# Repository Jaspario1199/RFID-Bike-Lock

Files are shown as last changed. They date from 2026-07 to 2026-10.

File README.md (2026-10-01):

# RFID Bike Lock

**Current DFM print prototype: [VELOX rev3f](releases/rev3f/README.md).** Use its 16 labeled STEP files and [build guide](releases/rev3f/PRINT_BUILD_REV3F.md), with the corrected model frozen at `releases/rev3f/snapshot/cad/cnc_casing_cq.py`. Coupons first; spool deferred; printer profile still pending. The older source/export folders and instructions below are retained as historical lineages and must not be mixed with rev3f.

A frame-mounted, RFID/NFC-unlocked bike lock with a retractable anti-cut steel cable.

The lock is a stainless-steel clamshell cylinder that clamps permanently onto the bike
frame over a compressible liner. A retractable steel cable lives on a spring-loaded spool
in the bottom of the housing; you pull it out, loop it through the wheel or around a rack,
and click the cable head into a latch on top. Tapping an authorized NFC fob (or phone —
see the design doc for the honest caveats) fires a solenoid that pulls the locking pin and
releases the cable, which then reels itself back in.

## Repo map — everything lives on one branch, organized by iteration

| Path | What it is |
|---|---|
| [`DESIGN.md`](DESIGN.md) | The full engineering design document: user workflow, electronics, wiring, power budget, mechanical dimensions, water/power hardening (§4.5), security analysis |
| [`BOM.md`](BOM.md) | Bill of materials — every part, quantity, estimated price (v0.8 all-M3 heat-set fastener standard + v0.8.3 weatherproofing items) |
| [`BUILD.md`](BUILD.md) | The authoritative bench build sequence + print-orientation table (`--dfm`) |
| [`ASSEMBLY.md`](ASSEMBLY.md) | Assembly/DFM audit + v0.8.3 weatherproofing steps (printed v0.8 lineage) |
| [`CAD_METHOD.md`](CAD_METHOD.md) | **Portable method doc** — how to model and verify mechanical parts with an agent: the gate catalogue, the iteration loop, honesty rules, and an opening prompt for a new project |
| [`BENCH_BUILD.md`](BENCH_BUILD.md) | **Start here for the electronics** — seven bench stages using only the delivered parts, with workarounds for the TP4056/AMS1117/cap that haven't arrived |
| [`WIRING.md`](WIRING.md) | **The electrical build in detail** — starts with the [wiring diagram](renders/electrical/wiring_diagram.png) — power domains, full net list, the RC522 3.3 V trap, driver-card layout, build order with expected measurements, failure table |
| [`CAD_AUDIT.md`](CAD_AUDIT.md) | **Build audit of the CNC casing (rev 3e)** — what `--audit` checks beyond the geometry gates (wire/connector envelopes, nuts, plugs, thread engagement, pin insertion, machining numerics), every defect it found and what moved |
| [`ASSEMBLY_CNC.md`](ASSEMBLY_CNC.md) | **The step-by-step build manual for the current CNC casing (rev 3e)** — print settings, every screw, bench checkpoints, stage-by-stage assembly, troubleshooting |
| [`INTERNALS.md`](INTERNALS.md) | **How every electronic mates inside** — per-part contact faces, screws, wiring paths, keyed to `renders/internals/` |
| [`CNC_CASING.md`](CNC_CASING.md) | **The machined-casing redesign** — CNC-first architecture (tube-half chassis + inside-out bolted boxes, bottom hinge pin + one guarded closure screw, centred spool puck, 60° swing gated, electronics stack-up gated, no inserts), DFM rulebook, decisions; model `cad/cnc_casing_cq.py`, STEP `cnc-design/step/`, drawings `cnc-design/drawings/`, renders `renders/cnc/` |
| [`firmware/`](firmware/) | Arduino sketch (v1, ready to flash) + bench bring-up guide |
| [`cad/bike_lock_cq.py`](cad/) | **The single source of truth**: parametric CadQuery model with built-in verification gates (`--gaps`, `--matrix`, `--sweep`, `--support`, `--dfm`) |
| [`newest-design/`](newest-design/) | **LEGACY printed CAD: frozen STEP set (v0.8.3) + MANIFEST** — print/import from here  |
| [`archive/`](archive/) | **Every previous iteration** (v0.2 → v0.7), one folder per version |
| `renders/` | Current assembly renders (closed / open / exploded) |
| `step/`, `stl/` | *Generated build outputs — gitignored; `python cad/bike_lock_cq.py` regenerates them* |

## Iteration index (newest first)

`releases/rev3f/` holds the current DFM print prototype; `newest-design/` holds the older printed lineage; each `archive/vX/` folder holds the frozen **STEP files** for that iteration (per-part
`placed/` set + full assembly + combined multibody) and a `MANIFEST.md` describing exactly
what changed. Older bulk formats (STL, doc snapshots) were trimmed for clarity — git
history preserves every byte.

| Iteration | Where | What it was |
|---|---|---|
| **v0.8.3** (legacy) | [`newest-design/`](newest-design/) | Environmental + DFM hardening: latch-bore & drum weep drains, TPU USB port plug, flush-printing cart, `--dfm` orientation scan, 6 V-rail power option, weatherproofing BOM |
| v0.8.2 | git history of `newest-design/` (MANIFEST §v0.8.2) | Structural audit: `--support` gate, all 17 under-supported heat-set holes fixed, driver card moved onto the pedestal cart (Option C) |
| v0.8 / v0.8.1 | same MANIFEST, §v0.8/§v0.8.1 | All-M3 heat-set fastener rebuild + snug-fit pocket tuning (Ø4.0 locked) + test coupon |
| v0.7 | [`archive/v0.7/`](archive/v0.7/) | Electronics as placed reference bodies; driver relocation; release process begins |
| v0.5–v0.6 | `cad/` git history | Spine+door consumer-install architecture; hinge rod; verification gates born |
| v0.3–v0.4 | [`archive/v0.3/`, `archive/v0.4/`](archive/) | Early CadQuery restructure + slim-top architecture (source + STEP kept) |
| v0.2 | [`archive/v0.2-openscad/`](archive/v0.2-openscad/) | Original OpenSCAD sketch |

## Status

**Design phase — firmware written, nothing physically built yet.** The next milestones
(detailed at the end of `DESIGN.md`) are:

1. Breadboard the electronics (Nano + PN532 + solenoid) and prove the unlock flow —
   the firmware and a step-by-step bring-up guide are waiting in `firmware/`
2. 3D-print the v1 housing (PETG first article; ASA for the outdoor unit) from
   `newest-design/` — print orientations in `BUILD.md` §3b
3. Fabricate the stainless housing

## Key design decisions so far

- **MCU:** Arduino Nano (upgrade path to 3.3 V Pro Mini for longer battery life)
- **Reader:** PN532 NFC module. Keys: NTAG213 sticker on the owner's phone case +
  keychain fobs (owner has an iPhone, which can't act as a hobby NFC key, so no
  companion app is planned)
- **Battery:** 103450 LiPo pouch 2000 mAh (protected) + TP4056 USB-C charge board — the 18650 stopped packaging at v0.4
- **Locking:** insert-to-lock needs **no power** (ramped cable head snaps past a spring pin);
  power is only used for the ~300 ms unlock pulse and brief scan windows
- **One-size-fits-all fit:** a printed TPU *finned* liner (fins bend instead of foam
  crushing, so it stays snug for years) covers Ø32–46 mm down tubes, closure
  detents fine-tune preload, and an included shim sleeve extends down to Ø27 mm skinny
  steel frames — see `DESIGN.md` §6.2
- **Self-guarding closure:** the only screw holding the housing shut sits at the bottom
  of the latch bore, so the locked cable head physically covers it — the case can't be
  unscrewed off the frame while the bike is locked (`DESIGN.md` §6.4). Note: as of the
  v0.6 CAD audit, four *other* service joints (hatch, spine cover, hinge cap, lid) are
  ordinary external screws reachable on the locked bike without unlocking anything —
  see `DESIGN.md` §7 for the honest security consequences and the production mitigation
  plan
- **v1 housing is 3D printed** (ASA for outdoor UV resistance); the latch keeps a steel
  pin + bushing even in plastic
- **Dead-battery behavior:** fail-secure — a dead battery stays locked, and the USB-C
  charge port doubles as the sole emergency input: any phone power bank runs the lock
  instantly for an unlock (`DESIGN.md` §8). There is no cam-lock backstop — it was
  deleted at v0.4 (the slim top never had a wall tall enough for its barrel)

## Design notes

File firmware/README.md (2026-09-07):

# Firmware

Three builds of the same lock, same behaviour and same key set — pick the one that matches
your board:

| Sketch | Board | Reader wiring |
|---|---|---|
| `rfid_bike_lock_esp32/` | **Arduino Nano ESP32** (3.3 V) — *the one in hand* | RC522 direct, **no level shifters** |
| `rfid_bike_lock_rc522/` | classic Nano / Uno (5 V) | RC522 via 1 k / 2 k dividers |
| `rfid_bike_lock/` | classic Nano / Uno (5 V) | PN532 over I2C |
| `rc522_test/` | **diagnostic** — Nano ESP32 | 40 lines: prints VersionReg + any card UID |
| `hw_selftest/` | **diagnostic** — Nano ESP32 | serial menu, exercises LEDs / buzzer / buttons / reader / solenoid / A0 one at a time |

## Nano ESP32 build

1. **Boards Manager** → install **"Arduino ESP32 Boards"**, then select *Arduino Nano ESP32*.
2. **Library Manager** → install **MFRC522** (by GithubCommunity).
3. Wire the RC522 straight to the board — both are 3.3 V parts:

| RC522 | Nano ESP32 |
|---|---|
| SDA (SS) | D10 |
| SCK | D13 |
| MOSI | D11 |
| MISO | D12 |
| RST | D4 |
| 3.3V | **3V3** |
| GND | GND |

4. Panel I/O is the same as the other builds: green button D3, red button D2, red LED D8,
   green LED D9, buzzer D6, solenoid gate D5, battery sense A0.

**Differences from the AVR builds, all platform plumbing:**

- **Deep sleep resets the chip**, so the whole scan window lives in `setup()` and the sketch
  deep-sleeps at the end of it. `loop()` never runs. Wake is ext0 on the green button.
- **Tags live in Preferences (NVS)**, not EEPROM. Same 8-byte record layout.
- **The ADC is 12-bit against 3.3 V**, so the battery maths differ. The 100 k : 100 k divider
  is unchanged.
- **`DEV_NO_SLEEP` is 1 by default.** Deep sleep kills the USB peripheral, so the IDE cannot
  reset the board into its bootloader and uploads fail with *"No DFU capable USB device
  available"* until you double-tap RESET by hand. With this switch on, the board idles awake
  between scan windows, USB stays alive and uploads just work. **Set it to 0 for the battery
  build** — idling awake costs roughly ten times the current of deep sleep, and the stage 7
  sleep measurement is meaningless with it on.
- **Upload failing anyway?** Double-tap the RESET button; the RGB LED pulses green in
  bootloader mode. Re-select the port (it changes in DFU mode) and upload.
- **Factory reset:** hold **both buttons** while powering up or pressing reset, for 1.5 s.
  Alternating LEDs and three beeps confirm it; the next wake re-enrolls a master.
- **Reader power gating is off by default** (`READER_POWER_GATED 0`). The IRF4905 you have is
  marginal at 3.3 V gate drive — its threshold is −2 to −4 V and 3.3 V logic can only reach
  −3.3 V. Fit the logic-level AO3401 from the SOT-23 kit before enabling it.

⚠️ **Honest caveat on battery life.** The Nano ESP32 is not a low-power board: the onboard
USB bridge, RGB LED and regulator all draw current in deep sleep, and reported figures are
milliamps rather than the microamps the bare ESP32-S3 can reach. Measure it (BENCH_BUILD stage
7) before trusting any battery-life estimate. If it comes in high, the fix is a bare
ESP32-S3 module or the 3.3 V Pro Mini path, not a firmware change.

---

Two sketches, one state machine (`../DESIGN.md` §5, pin map §4.2):

| Sketch | Reader | Use |
|---|---|---|
| `rfid_bike_lock_rc522/` | **RC522** (the Arduino kit board, SPI) | **build this first** — it is the reader the owner has, and the rev 3c housing is sized for it |
| `rfid_bike_lock/` | PN532 (I2C) | drop-in alternative if the RC522's range through the lid disappoints |

The two files differ only in the reader driver block (`pn532On/pn532Off/readTag`).

## RC522 wiring (hardware SPI)

| RC522 pin | Nano pin | Note |
|---|---|---|
| SDA (SS) | D10 | |
| SCK | D13 | |
| MOSI | D11 | |
| MISO | D12 | |
| RST | D4 | (D9 is the green LED) |
| IRQ | — | unused |
| 3.3V | **3V3 via the AO3401 gate** (D7) — bench step 1: straight to the Nano's 3V3 pin | the RC522 is a 3.3 V part; never 5 V on its VCC |
| GND | GND | |

## Panel I/O (both sketches)

| Part | Nano pin | Wiring |
|---|---|---|
| **GREEN button** (wake / open the scan window) | D3 (INT1) | one leg to D3, the other to GND; internal pullup. Only sleep wake source |
| **RED button** (tap = cancel the window, hold 5 s = admin mode) | D2 (INT0) | same, to GND |
| Red LED | D8 | through 470 Ω to GND |
| Green LED | D9 | through 470 Ω to GND |
| **Buzzer (ACTIVE)** | D6 | (+) to D6, (−) to GND. An active buzzer makes its own tone from DC |

Sounds: chirp on wake · two chirps on unlock · long buzz on a denied tag or a dead reader ·
three on admin mode · one long on low battery.

**Passive buzzer instead?** It needs a driven square wave. Replace the body of `beep()` with
`tone(PIN_BUZZER, 2700); delay(onMs); noTone(PIN_BUZZER);`. Note `tone()` uses Timer2 —
harmless here, but it will fight any library that wants that timer. The active one is the
simpler choice for the boxed unit; keep the passive one for the bench if you want pitch.

⚠️ A buzzer is a coil: keep it off the reader's gated rail and add a 1N5819 across it if you
ever drive it through a transistor rather than straight off the pin (an active buzzer draws
~25 mA, inside the Nano's 40 mA per-pin limit).

The Nano drives the RC522's SPI inputs at 5 V logic. Every RC522 kit tutorial does this and
it works, but it is out of spec; for the boxed unit put 1 kΩ in series with SS/SCK/MOSI/RST
(the MISO line is 3.3 V → Nano, fine).

## Setup

1. **Arduino IDE** → board *Arduino Nano*, processor *ATmega328P* (pick
   *Old Bootloader* if upload fails on a clone).
2. **Library:** install **Adafruit PN532** via Library Manager (pulls in Adafruit BusIO).
3. **PN532 module DIP switches → I2C mode:** on Elechouse-V3-style boards set
   `SEL0 = ON (1)`, `SEL1 = OFF (0)`. Boards silk-screen this next to the switches —
   trust the silkscreen if it disagrees.

## Bench bring-up (do these in order — don't wire everything at once)

| Step | Wire up | Expect |
|---|---|---|
| 1 | Nano + PN532 only (5 V, GND, A4→SDA, A5→SCL). Temporarily jumper D7's P-MOSFET out: power PN532 straight from 5 V. Serial monitor @115200 | On button press (D3→GND): `[wake]`, then tap a fob → `[scan] uid=…`. First tag ever tapped becomes **master** |
| 2 | Add the P-MOSFET power gate on D7 | Same behavior; PN532 LED only lights during the 10 s window |
| 3 | Add LEDs (D8 red, D9 green) | Denied tag → 2 red blinks; authorized → 1 s green |
| 4 | Add IRLZ44N + flyback diode + solenoid, **on a bench supply or fresh battery** | Authorized tap → 300 ms clunk |
| 5 | Measure sleep current (multimeter in series with battery, after the window expires) | Stock Nano: ~1.5–3 mA. If you see 20 mA+, the Nano never slept — check nothing is holding D3 low |

## Behavior recap

- **Press wake button** → 10 s scan window (green blip at start).
- **Authorized tag** → solenoid pulse, green 1 s, sleep.
- **Unknown tag** → red ×2, window stays open.
- **Low battery** (<3.5 V) → red ×3 right after wake, then continues normally.
- **First boot** → red/green alternating: the first tag tapped becomes the master
  (kept even through battery swaps; stored in EEPROM).
- **Hold button 5 s during the window** → admin mode: red/green alternating, tap
  **master** to confirm, then tap any tag to add (green ×3) or remove (red ×3) it.
  Master itself can't be removed. 15 s idle exits.
- **PN532 unresponsive** → fast red ×5 (check wiring/DIP switches).

## Config knobs (top of the sketch)

`SCAN_WINDOW_MS`, `SOLENOID_PULSE_MS`, `ADMIN_HOLD_MS`, `VBAT_LOW`, `MAX_TAGS`, and
`#define DEBUG` — comment DEBUG out for the battery-powered unit.

## Factory reset

Flash `File → Examples → EEPROM → eeprom_clear` once, then re-flash the lock sketch:
next boot re-runs master enrollment.

## Known v1 limitations (by design — see DESIGN.md)

- Auth is UID-matching only; UIDs are cloneable. v2 = challenge–response (HCE app).
- No cable-state sensor: an authorized tap pulses the solenoid whether or not the
  cable head is latched. Harmless; a latch microswitch is a v2 nicety.
- Phones can't act as keys directly (iPhone: Apple blocks it; Android: random UID per
  tap) — the permanent plan is fobs + an NTAG213 sticker on the phone case.

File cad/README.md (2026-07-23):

# CAD — parametric housing model (v0.6, CadQuery → STEP)

`bike_lock_cq.py` is the source of truth: a parametric [CadQuery](https://cadquery.readthedocs.io)
model that builds true BREP solids and exports **STEP** (SolidWorks-ready) and STL for
every part. Every dimension from DESIGN.md §6 is a named variable at the top of the file.

**Status: v0.6** — closure/hinge/verification overhaul on top of the v0.5 "spine + door"
architecture (still current: the door is a light arc panel that verifiably swings clear,
0–110°, machine-checked; pod, bay, and slim Y-axis drum all live on the body's right
side; the entry corridor is kept empty by construction). v0.6 was driven by a full
geometric audit that found and fixed 12 defects (D1–D12, all machine-confirmed) the old
verification missed: the closure screw now reaches a real M4 insert over a solid floor
instead of piercing into the tube cavity (D1/D2); the lid, spool cover, hatch, and bay
screws all land on working pilots instead of open cavities (D3–D6); the two glued end
plugs and their blind pins are gone, replaced by a single Ø4×~152 stainless **hinge rod**
with an integral turned head and a screwed **hinge cap** (owner request, no glue); the
sealed wire spine opened into a lay-in raceway closed by a screwed **spine_cover** (owner
request); the liner is retained by dovetail keys instead of adhesive/foam tape; the
battery bay was repacked so the LiPo and TP4056 no longer contest the same floor (D11);
and a merged pedestal/solenoid hole pair was separated (D12). Verification grew a
`--gaps` exact-distance mode, `--matrix`'s clash floor tightened to 0.01 mm³ (`--strict`
0.001), the sweep's moving set now includes `liner_left` (the old fixed-set sweep is
what hid D10, a liner gouge), and `--export-assembly` regenerates every STEP output off
one `placements()` table — see **Verification** below for all four modes.
v0.3 and v0.4 are preserved in `archive/`. Rendered and verified; nothing test-printed.

## Working in SolidWorks

**Fastest start: open `step/bike_lock_combined.step`** — all 12 parts positioned, as a
single multibody file (imports the same reliable way as the individual parts; each body
is separately selectable/hideable in the Solid Bodies folder). `bike_lock_assembly.step`
is the same content as a true STEP *assembly* with named, colored components — some
SolidWorks configurations open it blank; if so, untick Tools → Options → Import →
"Enable 3D Interconnect" and reopen, or just use the combined file. Neither carries
mates (STEP can't); parts are frozen in their correct positions. The optional `shim`
isn't included since it occupies the liner's space.

Open any `step/<part>.step` directly — each imports as a clean solid body (real faces,
direct-editable, measurable, assemblable, FEA-able). STEP carries no feature tree; to
iterate parametrically either edit `bike_lock_cq.py` and re-export, or rebuild a part
natively in SW using the parameter block as the spec.

**Native SW assembly in 2 minutes (no mates needed):** use `step/placed/01..12_*.step`
— every part is exported already moved/rotated into its final global position (including
the lid, spool cover, hinge rod, hinge cap, and spine cover). In a new assembly: Insert Component → pick a file →
press the green ✓ WITHOUT clicking in the viewport (drops at the assembly origin = its
correct position). Repeat through the numbered list; every component arrives placed and
Fixed. These are single-solid files — the format that imports/display most reliably.

**If a multibody/assembly STEP opens with a populated tree but a blank viewport:** show
the bodies (right-click Solid Bodies folder → Show), press `f`; if still blank, untick
Options → Performance → "Enhanced graphics performance" (restart), or as a last resort
enable software OpenGL — and verify the file itself in eDrawings.

To regenerate everything: `pip install cadquery` then `python bike_lock_cq.py`
(or `python bike_lock_cq.py lid drum_module` for specific parts).
`archive/v0.2-openscad/legacy_bike_lock_v02.scad` (repo root) is the retired OpenSCAD v0.2, kept for reference;
`render_v03.scad` only composites the exported STLs for preview renders.

## v0.7 part set (14 printed parts + 1 lathe rod + 11 electronics reference bodies)

v0.7 adds machine-verified ELECTRONICS PACKAGING: every BOM electronic is a
placed reference body (89+ numbering, green in renders, in `step/placed/` for
SolidWorks placement work - NOT printed), and every board has a modular
holder: the driver card (42×10.7 cut perfboard) sits on two Ø7 crown bosses
on the pod's −y strip (x66/x96, 2× M3 ST, <30 mm from the solenoid — the bay
perf rack was deleted, see BUILD.md §2), `nano_clamp` (edge-standing Nano in
a pod wall recess, clamp bar on crown bosses), TP4056 flat cradle rails (USB
correctly through the wall - the v0.5 vertical slot pointed it at the floor),
MT3608 end-posts on the pedestal tower, edge-standing LiPo with rail + wall +
block face. `89_mock_cable_head` models the latched cable head (Ø10 head,
ring groove at the plunger line, ~1.6 mm plunger engagement). The --gaps
table asserts the packaging: solenoid-to-lid 1.0, plunger-tail-to-button 1.0
(tail MUST be trimmed to x98), board recess seats, cell containment,
cable-head latch engagement - 292 checks.

| Part | Role |
|---|---|
| `body` (v0.7) | right clamp + asymmetric pod + latch boss + **open wire-spine raceway** + pedestal pads + swept closure pockets (D1/D2 fixed: the screw now reaches a real insert over a 3.7 mm solid floor instead of piercing the flange) |
| `door` (v0.7) | light arc panel + closure hook flange & low insert pad + hinge knuckles — verified to swing clear |
| `bay_module` (v0.7) | right-side brick (LiPo stood on edge to clear the TP4056 block — D11 — plus zip grids), slim Y-axis drum Ø68×32, snout; bolts by 4× M4 pan screws from inside the bore, now fully sub-flush (D5) |
| `bay_hatch` (v0.7) | bottom cover, doubles as the component **tray** (nesting pad + zip-anchor grid); 2× M3 machine screws into heat-sets on the external face — leave a service loop so pulling the tray doesn't strain the cell leads |
| `pedestal_cart` (v0.7) | solenoid mount on the pad system; attach pads moved off the solenoid holes (D12; VERIFY dims live here) |
| `lid` (v0.7) | window skin, NFC ring, button dish, PN532 pocket on drop-bosses (4× nylon M2.5, no tape); now has real pilots in the body rim (D3) — 4× M3 CS machine into heat-sets |
| `liner_right` / `liner_left` (v0.7) | TPU fit system, dovetail-keyed into each shell half (no adhesive); `liner_left` carries the closure's swept-form transit window (D10 fix) |
| `shim` (v0.7) | TPU fit-system C-ring extension (unchanged; not in `placements()` — occupies the liner's space) |
| `spool_cover` (v0.7) | outboard (+Y) drum face plate; screw circle moved onto the ring-wall boss and re-clocked so one screw sits on the vertical axis (D4/D5 fix) |
| `hinge_cap` (v0.7) | screwed tail cap capturing the hinge rod's 0.5 mm axial float — replaces the glued end plugs (D7) |
| `spine_cover` (v0.7) | screwed cover plate closing the wire raceway, drip grooves on the underside (owner request) |
| `hinge_rod` *(lathe, not printed)* (v0.7) | single Ø4.00×~152 mm 303-stainless rod, integral Ø6.0×1.6 turned head — one lathe op from Ø6 bar |

The pedestal still uses the standardized flat-pad system (12 mm pads, tops at z=32).

Assembly-audit fixes implemented (ASSEMBLY.md §3): **plunger-as-pin** (Ø6.6 channel, no
separate pin/spring/coupling), the **single hinge rod** (owner request, replacing the two
blind hinge pins and their glued end plugs — D7), and card-edge board pockets.

## v0.8 — all-M3 heat-set fastening (owner request)

For a super-refined printed prototype, **every threaded joint is now an M3 machine screw
into an M3 brass heat-set insert** — no self-tapping-into-plastic anywhere. The conversion
replaced every Ø2.5 self-tap pilot with an INS3 pocket (Ø4.1×6.5), switched the bay screws
from M4 self-tap to M3 socket-cap into inserts, dropped the closure screw from M4 to a short
M3 heat-set (Ø4.0×L3.8, the pad is only 3.4 mm deep), and moved all cover parts to
machine-flat countersinks (ISO 10642, 90°) since they now thread into inserts rather than
self-tap. Two carve-outs, both forced by an external part and both flagged in the BOM:
- **Solenoid → M2.5** — the JF-0530B's own mounting tabs are drilled M2.5; an M3 screw
  physically won't pass, so this one joint keeps an M2.5 brass heat-set.
- **PN532 → M3 nylon** — the antenna loop wraps the whole board perimeter, so brass/steel at
  the 4 corner holes sits in the 13.56 MHz field and kills read range; the M3 standard is
  kept but the screws are nylon into printed bosses (no insert). All 4 corners, no safe subset.

Two geometry side-effects were handled and re-gated to 0: the spool-cover screws couldn't take
a Ø4.1 insert in the 2.5 mm-thin ring wall, so each of the 3 stations gained a small inboard
buttress that backs the insert without fouling the cover recess; and two vestigial features
(the nano-*sled* foot pilots and the deleted perf-rack's hatch cartridge screws) were removed.
Gate after conversion: **0 violations / 292 checks · 0 clashes · sweep 0.00 · corridor clean.**

## Verification (v0.6)

`bike_lock_cq.py` runs an entry-corridor interference check on every export automatically.
Four more checks run as explicit CLI modes — none of these ship parts, they only assert
things about the model:

- **`--sweep`** — rotates the door **and `liner_left`** 0–110° about the hinge against
  everything else and asserts 0 mm³ overlap at every step. The moving set used to be
  door-only against a body+bay+lid-only fixed set; that gap is exactly what hid D10 (a
  25.5 mm³ gouge through `liner_right`'s base ring at θ=10° that the body-side relief
  never covered because the liner never got its own).
- **`--matrix`** — full pairwise static-interference check over every part in
  `placements()`. The true-clash floor tightened from 1 mm³ to **0.01 mm³** (an OCC-noise
  study); `--strict` drops it further to **0.001 mm³**, which stays clean at exact
  tangency but is finer than FDM tolerance can act on, so it's opt-in.
- **`--gaps`** — exact minimum-distance check (`BRepExtrema_DistShapeShape`) on every
  placed pair, layered on top of the boolean clash gate so a true overlap and an intended
  tight fit can't be confused. Each pair is checked against `GAP_SPECS`: a `(min, max)`
  mm band (e.g. liner-in-bore 0.05–0.30), the `CONTACT_OK` sentinel for clamped faying
  faces where 0.00 mm is correct and only actual interpenetration should fail (seam/hook,
  pod rim, pedestal pads, hinge-rod head seat, hinge-cap seat, spine-cover seat), or the
  plain clash-only floor if the pair is unlisted. `feature_probes()` adds local box probes
  for fits a whole-pair distance can't isolate on its own — a 0.00 mm contact anywhere
  else on the same pair would swamp the measurement otherwise — currently the knuckle
  axial gap (0.6–1.0 mm at 6 x-stations, asserting `hinge_gap`'s ~0.8 mm net float) and
  the hinge-rod running-bore fit (0.05–0.15 mm, checked separately in `body` and `door`).
- **`--export-assembly`** — regenerates `step/placed/`, the combined multibody STEP, and
  the assembly STEP, all off the same `placements()` table `--matrix` and `--gaps` read,
  so the three outputs can't drift apart from each other.

All four currently PASS.

## Design principles applied in v0.2

Standard FDM design-for-manufacturing + product-design practice:

- **One radius family** (R14 belt / R11 pod / R3 details / 1.2 mm edge breaks) so every
  surface looks like it belongs to the same object.
- **Drafted walls**: the pod tapers 1.8 mm base→lid, with the interior drafted the same
  amount → **uniform ~3 mm walls** everywhere (no massive solids; the latch boss and
  solenoid pedestal are gusseted/hollowed instead of solid).
- **The part line is a design line**: the closure skirt is the left half of a full
  wrap-around **belt band**, separated from the pod by a 0.8 mm shadow-gap groove — the
  seam reads as intentional, and the hidden-screw closure lives inside it.
- **Fairings, not intersections**: pod→tube and drum→body transitions are blended
  (teardrop), keeping overhangs ≤45° so the shells print without heavy support.
- **Chamfered bottom edges** everywhere a part meets the build plate; countersunk lid
  screws; recessed USB niche; embossed NFC target ring so the user knows where to tap.
- **Wiring is modeled, not implied**: two clip-lip floor raceways (RF-zone ribbon x4–54,
  power/solenoid run x60–100), a driver tray over the Nano bay with wire notches and
  zip-tie holes, two battery saddles giving the 18650 holder a level bed (with zip-tie
  pass-unders), and two mushroom strain-relief posts for the lid's service loop.

## Print guide

| Part | Material | Orientation / notes |
|---|---|---|
| body (shell_right) | PETG first / ASA outdoors | pod-opening up; light support under belt + spine rib |
| door (shell_left) | PETG / ASA | split-face down, near-zero support |
| bay_module | PETG / ASA | hatch-faces down; supports under the drum ring arc only |
| bay_hatch | PETG / ASA | flat, no support — now the component tray, see drill-out note below |
| lid | PETG / ASA | top-face down on a smooth sheet (window skin + NFC ring print first) |
| pedestal_cart, hinge_cap | PETG | flat side down, minutes each |
| spine_cover | PETG / ASA | curved face up; dry-fit before drilling — see orientation/warp VERIFY below |
| liner halves, shim | TPU 95A | 2 perimeters, 15% infill, ~25 mm/s, fins vertical; keys separate — see dovetail VERIFY below |
| hinge_rod | 303 stainless bar, lathe | not printed — see "Hinge" in the change notes for the lathe callouts |

### Drill-out / bench ops after printing (new in v0.6)

- **Hinge bore.** Modeled finished at Ø4.2 (`HINGE_BORE`), but FDM print holes come out
  undersized and drooped — don't trust the as-printed bore. **Drill Ø4.2 straight through
  the body and door with the two shells closed and clamped together** (i.e. after the
  liner/closure dry-fit, not before): this crosses 8 interrupted knuckle segments, each
  ≤14 mm long (L:D ≤3.5), so it's a series of short through-holes, not deep-hole drilling
  — the printed pilot self-centers the bit. Blow out swarf before the liner or rod goes in.
- **Plunger channel.** `pin_ch_d` is modeled at `plunger_d + 0.6` = 6.6 mm. Ream to 6.5 mm
  only once the real JF-0530B plunger is measured — VERIFY before committing to the ream.
- **Dovetail groove.** The 60° groove/key pair is orientation-sensitive on FDM (layer
  lines cross the flank at an angle); print and slide-fit a short test length before
  committing a full liner print — see "Suggested first prints" below.
- **Spine cover.** Dry-fit on the r35 rabbet ledge before drilling the 2× M3 pilots — a
  bowed or under-radius print won't seat flush, and the 0.5 mm shadow-gap reveal makes
  any unevenness obvious.
- **Hatch/tray.** `bay_hatch` is now the component tray (nesting pad + zip-anchor grid),
  not just a cover — check the nesting pad registers flush with the remaining bay floor
  before loading components, and leave a lead service loop so removing the tray doesn't
  strain the LiPo/TP4056 wiring.

## VERIFY before printing (measure your actual parts)

- `sol_hole_dx` — mounting-hole spacing of the JF-0530B you receive (clones vary) —
  merged with the pedestal attach holes in v0.5 (D12); confirm before installing the
  M2.5 heat-sets
- `pn532_l/w/t` — your PN532 board (clone boards vary a couple of mm)
- PN532 corner mounting holes — `PN532_HOLE_INSET` (2.54 mm) assumes Elechouse V3
  corner holes at Ø3; clones may lack them, in which case the printed corner clips (same
  drop-bosses) are the fallback
- `button_d` — thread diameter of your wake button (12 mm nominal)
- ST flat-head countersink angle — modeled at 90° (`M3_ST_CS_D`/`M3_ST_CS_T`); confirm
  your self-tap screws are 80° or 90° before cutting countersinks to depth
- M4-short heat-set (Ø5.6×L3, closure) and M3/M2.5 brass insert dimensions — confirm the
  actual insert OD/length you buy against `INS4_D`, `INS3_D`/`INS3_T`, `INS25_D`/`INS25_T`
  before drilling insert pockets
- Plunger diameter — `pin_ch_d` (6.6 mm) is a placeholder for the 6.5 mm reamed channel;
  confirm against the real plunger (see drill-out note above)
- TP4056 slot width — confirm against your board before trusting the D11 bay repack
- Dovetail groove print-orientation test — slide-fit a short liner slice before running
  a full liner print
- Spine cover warp/orientation test — dry-fit flush on the rabbet ledge before drilling
- LiPo edge-stand fit — measure your actual 103450 pouch (`lipo_l/w/t`) against the
  on-edge bay repack (D11) before trusting it packable
- Donor spool: the drum interior is Ø61 × 28.5 (v0.5 slim drum) — check the reel you gut fits, or resize
  `drum_od`/`drum_w` (frame otherwise cut for 34.5 × 51 × 11 / 103450 + margin — measure
  yours against `lipo_*`)

## Known simplifications (TODO after first fit-check print)

1. Closure lip is a single snug hook — the 3 preload detent depths (DESIGN.md §6.4) get
   added once the on-bike fit is measured; `clr` (0.5) needs a fit print.
2. ~~Liner halves rely on friction + adhesive; dovetail keys into the shell come later.~~
   **SOLVED in v0.6:** a full-length 60° dovetail groove per shell half (mid-arc, one
   straight axial pass) with 4× 28 mm TPU keys sliding in from the front, captive both
   ways (blind stop + click-bump) — no adhesive anywhere in the liner retention path.
3. Shim is a plain C-ring approximation of the clip-over design.
4. Lid uses 4 M3 screws. In v0.6 these landed on **real pilots in the body rim for the
   first time** (D3 — v0.5's screws had no working pilots at all, two of them even fell
   inside the PN532 window's 1.2 mm skin) and drive into brass M3 heat-sets, so it's now
   an actual fastened joint rather than a nominal one. It is still externally removable
   on the locked bike — that's now documented as one of four such joints (hatch, spine
   cover, hinge cap, lid), not a uniquely accepted exception; see DESIGN.md §7 for the
   full consequence list and the production mitigation plan (security/one-way heads,
   staking, eventual hidden lid fastening).
5. Spool spring anchoring is not modeled — depends on the donor reel's spring.
6. The bay tunnels are functional but unblended boxes — the v0.6 industrial-design pass
   (bay-brick bottom chamfer, knuckle chamfers, lid inset/reveal, radius family) softened
   the visible skin, but a full cosmetic fairing pass on the bay tunnels still comes
   after fit is proven. The wire-spine rib itself is gone: it's now an open raceway under
   a separate screwed `spine_cover` (see the part table above), not a molded-in band.
7. The plunger nose needs its 45° ramp filed/ground by hand — 10 minutes with a file;
   the cable-head groove width (≥6.5 mm) must match, noted in DESIGN.md §6.4.

## Suggested first prints (cheap fit checks before the big ones)

1. **Liner test ring**: a 30 mm-long slice of the liner on a 30 mm slice of shell — clamp
   it on the actual bike, judge fin grip across a couple of other bikes too.
2. **Latch block only**: cut the latch boss region (X 45–115) using OpenSCAD's
   intersection with a cube — test bore, pin channel, solenoid pedestal, and the bench-mule
   square tang (DESIGN.md §6.4) with the real solenoid before printing full shells.

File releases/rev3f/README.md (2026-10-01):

# VELOX rev3f — prototype print-stage STEP files

16 individual solid STEP files, in millimetres, oriented as the build guide suggests and placed at Z=0. File names include order, part, material and revision. No assembly or purchased-component reference is included in the STEP folders.

1. Print the two fit coupons first, in their supplied orientations, and test the actual latch hardware.
2. Print electronics and latch parts after accepting the fits. The printed latch parts are fit/motion prototypes.
3. Frame parts are optional today. The complete clamp hinge uses the deferred A3 housing; these parts alone do not form a complete lock.
4. Print TPU liners after checking the stud press fit; print a small representative fit section first.

A3 spool housing, A4 cover and the metal hinge pin are excluded. Supports still require slicer preview; use the included build guide. Geometry audits passed; real component fit, screw retention and printer calibration remain physical checks.

No printer-settings archive was found in the repository files/history, releases or PR. No profile has been applied and no G-code is included. Do not mix with rev3e or v0.8.3 parts.

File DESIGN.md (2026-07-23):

# RFID Bike Lock — Design Document

> **v0.8 fastening rebuild (owner request):** every threaded joint is now an M3 machine
> screw into an M3 brass heat-set insert (super-refined printed prototype). Two carve-outs,
> both forced by an external part: the solenoid stays M2.5 (its tabs are drilled M2.5) and
> the PN532 stays M3 nylon into printed bosses (brass at the antenna corners kills read
> range). See cad/README.md "v0.8" and BOM items 23a–g. Gate after conversion: 0/292.

*Rev 0.1 — first full write-up of the concept. Everything here is open to change; sections
marked ⚠️ are known problems we still need to solve.*

---

## 1. Concept summary

A permanently frame-mounted bike lock. The housing is a stainless-steel clamshell cylinder
that clamps around the bike's down tube over a compressible liner. Inside:

- **Bottom pod:** a spool holding ~1.5 m of plastic-coated steel cable, wound against a
  spiral return spring (tape-measure / retractable-dog-leash style) so the cable
  self-retracts.
- **Top pod:** the electronics — Arduino Nano, PN532 NFC reader (face-up, so you tap the
  top of the lock), a pull-type linear solenoid, an 18650 battery with USB-C charging, and
  the cable latch.

**Locking is mechanical and needs no power:** the cable's mushroom-shaped head has a
ramped face, so pushing it into the latch shoves the spring-loaded locking pin aside until
the pin snaps into the head's groove. **Unlocking needs power:** tap an authorized
tag/fob, the solenoid pulls the pin for ~300 ms, a small ejector spring pops the head out,
and the spool reels the cable home.

```
                       tap fob here
                            ▼
                ┌───────[PN532 face]──────┐
                │  latch ○   electronics  │   ← top pod (latch, solenoid,
                ├─────────────────────────┤      Nano, PN532, 18650)
hook joint ──► ═╪═════════════════════════╪═   ← flanges interlock; the only screw
   (no exposed screws)                           hides at the bottom of the latch bore
                │ ░░░ compressible liner ░│
                │ ░░┌─────────────────┐░░ │
                │ ░░│   BIKE FRAME    │░░ │   ← clamp section
                │ ░░│    (down tube)  │░░ │
                │ ░░└─────────────────┘░░ │
                ├────hinge─────────hinge──┤   ← hinges along the bottom
                │      cable spool +      │
                │      spiral spring      │   ← bottom pod
                └───────────○─────────────┘
                            ▲
                     cable exits here
```

---

## 2. User workflow

### One-time install
1. Open the clamshell (hinges on the bottom); clip in the shim sleeve first if your tube
   is skinny (Ø27–32 mm — vintage/steel frames).
2. Close it around the down tube: slide the flanges' hook joint together, pick the tongue
   detent that gives a snug fit, and drive the single M4 closure screw home at the bottom
   of the latch bore (long 2.5 mm hex key). The liner fins deflect and grip the frame.
3. Enroll your tags (see below).

### Locking the bike (no power used)
1. Pull the cable out of the bottom pod (spool spring provides light resistance).
2. Loop it through the front wheel and/or around a rack.
3. Push the cable head into the top latch until it clicks. Done — the electronics never
   woke up.

### Unlocking
1. Press the **wake button** on the top face. Status LED blinks green: reader is live for
   a 10-second scan window.
2. Tap your fob / NFC sticker / (Android) phone on the top face.
3. Authorized → solenoid pulses, head pops out, cable auto-retracts, LED solid green 1 s.
4. Unauthorized → LED blinks red twice, window stays open until the 10 s expire.
5. No tap within 10 s → everything goes back to sleep.

### Enrolling / removing tags
- Hold the wake button for 5 s → LED alternates red/green → tap the **master fob**
  (enrolled at first boot) → now in admin mode:
  - Tap an unknown tag → added (green triple-blink).
  - Tap a known tag → removed (red triple-blink).
  - 15 s idle → exit admin mode.
- Tag UIDs are stored in the Nano's EEPROM (survives battery death). Capacity: dozens of
  tags; we'll cap at 10.

### Charging / low battery
- LED gives a red triple-blink after any wake when the battery is below ~3.5 V.
- Charge through the USB-C port (TP4056 board) with the same cable as your phone.
- Battery state is checked on every wake via a voltage divider.

---

## 3. RFID/NFC reader choice — and the truth about phones

**Chosen module: PN532** (Elechouse V3 or clone, ~$8, 40 × 43 mm, I2C mode).

You asked for the lowest-power small reader **that can read your phone**. Reading a phone
means NFC (13.56 MHz, ISO 14443), and among hobby modules only the PN532 speaks the
protocols phones use. The popular cheap RC522 **cannot** talk to phones.

⚠️ **Honest phone caveats — read this before counting on phone-unlock:**

| Key type | Works? | Notes |
|---|---|---|
| MIFARE Classic fob / card (~$0.50) | ✅ Reliable | The v1 workhorse. |
| NTAG213 **sticker** on your phone case (~$0.30) | ✅ Reliable | This is the practical way to "unlock with your phone." |
| **Android phone** via HCE app | ⚠️ Possible, v2 | Android randomizes its UID on every tap, so simple UID matching fails. It works properly with a small companion app doing challenge–response (APDU/AID) — a genuinely better-than-fob security level, but real firmware+app work. Planned for v2. |
| **iPhone** | ❌ Not feasible | Apple only lets Wallet passes act as cards; a hobby lock can't enroll one. Use the sticker approach. |

**Resolved:** the owner carries an iPhone, so the permanent key plan is **NTAG213 sticker
on the phone case + keychain fobs**. The Android HCE companion app is dropped from the
roadmap (kept below as reference only, in case an Android user ever builds this).

**Power reality:** the PN532's RF field draws 50–100 mA while scanning — you cannot leave
it polling 24/7 on a battery. Two design decisions fix this:

1. The PN532's power rail is **switched by a P-MOSFET** — it is fully off except during
   the 10 s scan window (its own "low-power" modes still leak too much on clone boards).
2. Scanning only happens after a **wake-button press**. No button, no field, no drain.

---

## 4. Electronics

### 4.1 Block diagram

```
                    USB-C
                      │
              ┌───────▼────────┐
              │ TP4056 charger │
              │  + DW01 protect│
              └───────┬────────┘
                      │
               18650 Li-ion (2500 mAh, 3.0–4.2 V)
                      │
        ┌─────────────┤
        │             │
        │      ┌──────▼──────┐
        │      │ MT3608 boost│   + 1000 µF reservoir cap on the 5 V rail
        │      │   → 5 V     │
        │      └──────┬──────┘
        │             ├──────────────────────┐
        │             │               ┌──────▼──────┐
        │             │               │  N-MOSFET   │◄── D5 (300 ms pulse)
        │             │               │  IRLZ44N    │
        │             │               └──────┬──────┘
        │      ┌──────▼──────────┐    ┌──────▼──────┐
        │      │  Arduino Nano   │    │  Solenoid   │ JF-0530B 6 V coil
        │      │  (5V pin)       │    │  (~250 mA)  │ + flyback diode
        │      └──┬───┬───┬───┬──┘    └─────────────┘
        │         │   │   │   │
        │   I2C ──┘   │   │   └── D3: wake button (pin-change interrupt)
        │   (A4/A5)   │   └────── D8/D9: red/green status LEDs
        │      │      └── D7 ──► P-MOSFET gate (PN532 power switch)
        │  ┌───▼────┐
        │  │ PN532  │◄── 5 V via P-MOSFET (off when asleep)
        │  └────────┘
        └── A0: battery voltage divider (2 × 100 kΩ)
```

### 4.2 Pin map

| Nano pin | Connects to | Purpose |
|---|---|---|
| A4 (SDA), A5 (SCL) | PN532 (I2C mode, DIP switches set to I2C) | Tag reading |
| D7 | P-MOSFET gate (e.g. AO3401 + pullup) | Hard power switch for PN532 |
| D3 (INT1) | Wake pushbutton → GND (internal pullup) | Wake from power-down sleep |
| D5 | IRLZ44N gate via 100 Ω, 100 kΩ pulldown | Solenoid pulse |
| D8 / D9 | Red / green LED via 470 Ω | Status |
| A0 | 100 kΩ/100 kΩ divider from battery + | Battery voltage sense |
| 5V | MT3608 output | System power |

Solenoid wiring: 5 V rail → solenoid → IRLZ44N drain, source → GND. 1N5819 flyback diode
across the solenoid coil (cathode to +). 1000 µF electrolytic across the 5 V rail near
the solenoid to stiffen the pulse.

**The solenoid runs off the regulated 5 V rail.** The JF-0530B has no 5 V winding — it
ships as 6 V / 12 V / 24 V — so we use the **6 V variant** at 5 V: ~20 Ω coil → ~250 mA,
which the MT3608 (2 A switch) supplies without disturbing the Nano, and the pulse strength
no longer sags with battery voltage. Expect roughly 70% of rated force at 5 V on a 6 V
coil; the pin return spring is sized to what the solenoid *actually* pulls — measure in
prototyping. If the measured pull is short, the fallback is the 12 V variant fed by its
own dedicated mini-boost, pulsed the same way.

### 4.3 Solenoid

- **JF-0530B pull-type, 6 V winding** (no 5 V version exists; 6/12/24 V are the options),
  ~20 Ω coil → ~250 mA on our 5 V rail. Rated 5 N force / 10 mm max stroke — we use ~4 mm
  of it, where pull is strongest. ⚠️ Clone specs vary wildly between sellers (some list
  the 12 V coil at 1 A); measure the actual pull force of the unit you receive.
- Verified dimensions: **body 30 × 13 × 15 mm, plunger Ø6 × 58 mm** — the full
  body+plunger train is ~65 mm long, which drives the layout in §6.5. The plunger tail can
  be trimmed to length (it's plain rod). M2.5 mounting holes, 20 cm leads.
- Energized for **300 ms max** per unlock. Duty cycle is effectively zero, so no heating
  concerns.
- Energy per unlock ≈ 0.25 A × 0.3 s ≈ **0.02 mAh** — even 20 unlocks/day is under
  0.5 mAh/day, i.e. the solenoid is *not* the battery problem; standby drain is.

### 4.4 Power budget & battery life

Battery (v0.4): one protected **103450 LiPo pouch, 2000 mAh** nominal, ~1600 mAh usable
above the cutoff (the 18650 of earlier revs doesn't package in the v0.4 bottom bay).

| State | Draw | Time share |
|---|---|---|
| Sleep (Nano power-down, PN532 off, boost quiescent) | ~1.5–3 mA (stock Nano; the USB chip + regulator leak) | ~99.9% |
| Scan window (Nano awake + PN532 field on) | ~90–130 mA | 10 s × ~6/day |
| Solenoid pulse | ~250 mA | 0.3 s × ~6/day |

Daily consumption ≈ (2.5 mA × 24 h) + (0.11 A × 60 s)/3600 + (0.25 A × 1.8 s)/3600
≈ 60 + 1.8 + 0.13 ≈ **62 mAh/day → roughly 3.5–4 weeks per charge on the 2000 mAh LiPo.**

The standby leak dominates everything. Upgrade path (v2): swap the Nano for a **3.3 V/8 MHz
Pro Mini with its regulator and power LED removed** → sleep current drops to ~10 µA,
boost converter deleted (everything runs at battery voltage), and battery life becomes
**6–12 months**. The firmware is identical. Recommended as soon as the breadboard
prototype works.

⚠️ Winter note: Li-ion loses capacity below 0 °C and must not be *charged* below 0 °C.
Fine for College Station; document it anyway.

### 4.5 v0.8.3 hardening addendum — water ingress + power refinements

**Water (the lock lives outdoors, rain + wheel spray; none of this was addressed before
v0.8.3).** Machine-verified CAD changes plus documented seals, worst paths first:

| Ingress path | Severity | v0.8.3 resolution |
|---|---|---|
| **Latch bore** — Ø11 × 26 cup open to the sky at the lid; rain pools on the z30 floor around the consumer screw; a freeze seizes the plunger | HIGH | **Ø2.2 weep drilled in the CAD**, offset 3.5 mm from the screw axis, draining the bore floor into the tube bore (water exits axially along the liner). Plus: silicone grease on the plunger at assembly (§ASSEMBLY) |
| **Drum void** — the snout enters at z≈−74 but the void bottoms at −90.5: a 16 mm bucket under the spool + return spring | HIGH | **Ø2.5 weep drilled in the CAD** at the ring's lowest point; the void now drains instead of rusting the donor spring |
| **USB-C port** — open slot in the bay wall, wheel-spray zone, straight shot onto the TP4056 | HIGH | **New `usb_plug` TPU part** (printed, tethered by lanyard hole): squish-fit stem + flange, pull to charge |
| **Lid seam** — 0.5 mm open reveal around the lid perimeter, dripping onto the PN532/Nano | MED | 1 mm **EPDM foam tape gasket** on the pod rim, compressed by the 4 lid screws (BOM 30a). The reveal stays (cosmetic); the tape is the water stop behind it |
| **LED holes** — 2 × Ø3.3 through the lid top inside a water-collecting recess | MED | LEDs inserted from below, domes potted with **clear RTV silicone** (BOM 30b); the recess then sheds instead of pooling |
| **Bay hatch seam** — underside, spray zone | LOW | Nesting pad + downward orientation already shed most of it; optional strip of the same EPDM tape on the pad lip; the tray's zip holes double as weeps |
| Wake button / spine cover | LOW | Button is a *sealed* panel-mount type (BOM 12, its own nut gasket); spine cover already has drip grooves |

**Power refinements:**

- **Full solenoid force with zero new parts (recommended before the 12 V fallback):** trim
  the MT3608 to **6.0 V** instead of 5.0. Solenoid gets its full rated winding voltage
  (~300 mA, 100% force — the 70%-at-5V compromise in §4.2 disappears). The Nano moves from
  the 5 V pin to **VIN** (its onboard AMS1117 makes 5 V from the 6 V rail), and the PN532 +
  LEDs feed from the **Nano's 5 V pin** (AMS1117 output, 800 mA headroom vs ~150 mA peak
  load) through the existing P-FET gate. Two wires move and one pot turns; try this FIRST
  if measured pull force is short. (Cost: the AMS1117 adds ~5 mA awake — irrelevant next to
  the PN532 field — and ~1 mA asleep, which the v2 Pro-Mini path deletes anyway.)
- **Charging honesty (TP4056 has no load sharing):** the basic board charges the cell while
  the system is still connected, so a scan burst during charge can fool the termination
  detection (charge "completes" early, or cycles). Prototype rule: **charge with the lock
  asleep and don't wake it mid-charge**; the clean fix (load-sharing P-FET between charger
  and load, or a TP4056 board with OUT+/OUT− wired as designed) is a v2 item logged in §9.
- **Standby reality check** (unchanged math, restated with the boost included): MT3608
  quiescent ~1–1.5 mA is inside the §4.4 sleep row — the ~62 mAh/day → **3.5–4 week**
  figure already carries it. The v2 Pro-Mini/no-boost path remains the real fix.

---

## 5. Firmware design (state machine)

```
 POWER_ON ──► first boot? ──yes──► ENROLL_MASTER (first tag tapped = master, store in EEPROM)
     │                                   │
     ▼                                   ▼
   SLEEP  ◄──────────────────────────────┘
     │  (power-down, all peripherals off, ~µA on Pro Mini)
     │  wake button (INT1)
     ▼
   WAKE ──► check battery (A0) ──► low? blink red 3× (but continue)
     │
     ▼
   SCAN (PN532 powered, 10 s window)
     │ tag read
     ▼
   AUTH ──► UID in EEPROM list? ──no──► blink red 2×, back to SCAN
     │ yes
     ▼
   UNLOCK: solenoid HIGH 300 ms → LED green 1 s → SLEEP

   (button held 5 s during WAKE) ──► ADMIN: master tap required,
        then tap-to-add / tap-to-remove, 15 s timeout → SLEEP
```

Implementation notes:
- `avr/sleep.h` power-down mode + pin-change wake on D3; disable ADC/brown-out during sleep.
- Adafruit_PN532 library, I2C mode.
- EEPROM layout: `[magic byte][count][master UID 7B][UID slots 10 × 7B]`.
- Debounce unlocks: ignore repeat reads of the same UID for 2 s.
- v2 (Android HCE): replace UID matching with an APDU SELECT of our custom AID + an HMAC
  challenge–response against a key shared with the companion app. Also fixes clone-ability
  of MIFARE UIDs.

⚠️ **Security honesty:** v1 authenticates by UID only, and MIFARE UIDs can be cloned with
a $20 gadget by someone who taps your fob. For a bike lock this is an acceptable v1 risk
(the cable is the weaker link anyway — see §7), but v2 challenge–response closes it.

---

## 6. Mechanical design

**v1 housing is 3D printed** (see §6.2 print spec); the stainless shell moves to a later
phase once the geometry is proven. All dimensions below apply to both.

*CAD v0.6 (CadQuery/STEP) implements this section as a **12-printed-part + 1-lathe-part
assembly** (was a 13-part all-printed count through v0.3 — the two Ø3 mm hinge pins and
their glued end plugs are gone, replaced by one lathe-turned hinge rod + a screwed cap;
no glue anywhere in the current assembly): the two shells stay structural/integral (clamp
+ pod + belt + latch boss), the spool drum is a separate zero-support module bolted from
inside the clamp bore (screws reachable only when unlocked), and all interior furniture
is drop-in cartridges on a standard pad system — full rationale in ASSEMBLY.md and
cad/README.md.*

### 6.1 Overall envelope

**One-size-fits-all requirement:** one product, no size variants, snug on the range of
average down tubes. Design targets:

- **Core range: Ø32–46 mm** (modern alu/steel road + most MTB) with the standard liner
- **Extended range: Ø27–32 mm** (skinny steel/vintage frames) via an included clip-in shim
  sleeve — still "in the box," no separate SKU
- Out of scope for v1: non-round aero/carbon tubes (Ø50 mm+ ovals). Flagged, not solved.

No single feature spans Ø27–46 mm, so the fit stacks **three** mechanisms — see §6.2.

| Element | Dimension | Notes |
|---|---|---|
| Clamp shell ID | Ø54 mm | v1: printed, 4 mm wall → OD Ø62 mm. Steel version: 304, 1.5 mm wall → OD Ø57 mm |
| Clamp length | 150 mm | sized by the top pod (§6.6 packing study): battery + latch + antenna zones can't overlap, so the pod needs 150 mm and the clamp matches it. Bonus: more grip, less rocking |
| Liner | Printed TPU ribbed sleeve, 12 mm radial fins (§6.2) | free bore Ø30 mm; grips Ø32–46 mm tubes |
| Shim sleeve | Clip-in TPU ring, 3 mm solid + its own 4 mm fins | extends range down to Ø27 mm |
| Hinges | Printed knuckles + **one Ø4.0 mm 303-stainless rod** (~152 mm, integral Ø6×1.6 head, running fit in a finished Ø4.2 bore) the full length of the bottom seam, retained by a screwed hinge cap at the rear (§6.8/§6.9); steel version: same single-rod axis, riveted piano hinge | replaces the two Ø3 mm pins + glued end plugs (through v0.5) |
| Closure | Full-length hooked tongue-and-groove flange joint + **one M4×8 screw into a short M4 heat-set at the bottom of the latch bore** (§6.4) | the locked cable head covers the only screw → housing can't be opened while the bike is locked. Preload adjustment: **3 tongue detent depths only** (≈ ±2.5 mm effective clamp diameter) — the single fixed-diameter hinge rod removes the hinge-side preload freedom v0.5 relied on; the detents remain the sole adjustment and are still unmodeled in CAD (TODO) |
| Top pod (electronics) | 150 × 55 mm footprint, lid 34 mm above the shell crown | full internal layout + wiring plan in §6.6; the lid over the PN532 antenna must be plastic even on the steel version (13.56 MHz passes through plastic, not steel) |
| Bottom pod (spool) | Ø95 mm × 34 mm drum hanging under shell | |
| Total added weight | v1 printed ~500–650 g; steel ~750–900 g | comparable to a mid U-lock |

### 6.2 One-size-fits-all liner — material & geometry

**Why solid foam fails this requirement:** a foam thick enough to grip a Ø32 mm tube
inside a Ø54 mm shell is 11 mm thick; on a Ø46 mm tube that same foam must squash to
4 mm — ~65% compression, held permanently, outdoors. Every foam takes *compression set*
under those conditions (it never springs back), so the lock is loose within months. Foam
also can't be "cut to tube size" in a one-size product — that was the old spec, now dead.

**Chosen approach: a printed TPU finned liner.** Instead of compressing material
volumetrically, angled rubber fins *bend* out of the way — like the ribs inside a bike
computer mount. Bending strain is far below the material's set threshold, so fins stay
springy for years, and the grip force is nearly constant across the whole tube range.

```
   shell wall ─►│
               │╲╲╲╲╲╲╲   ← fins angled ~30° off radial,
               │ ╲╲╲╲╲╲     12 mm tall, 1.4 mm thick,
               │  (tube)     ~24 around the circumference
               │ ╱╱╱╱╱╱      small tube: fins barely deflect
               │╱╱╱╱╱╱╱      big tube: fins fold to ~35° — still elastic
```

| Liner spec | Value |
|---|---|
| Material | TPU 95A (printable on any hobby printer that does flexibles) |
| Form | Two half-sleeves, dovetail-keyed into each shell half (replaceable — a wear part by design) |
| Fins | 12 mm tall × 1.4 mm thick, 30° lean, 24 per circumference, running axially |
| Base | 2 mm solid backing bonded/keyed to shell |
| Free bore | Ø30 mm → 1–2 mm fin preload even on the smallest core-range tube |
| Grip aids | Fin tips textured; TPU is naturally high-friction on paint without marring it |

Material trade study (for the record):

| Material | Snug across range | Lasts outdoors (set/UV/temp) | Cost | Verdict |
|---|---|---|---|---|
| **TPU 95A printed fins** | ✅ bending, not crushing | ✅ excellent abrasion/tear, good UV, fins replaceable | ~$2 of filament | **v1 and probably final** |
| Silicone sponge sheet | ⚠️ ~50% compression max | ✅ best-in-class compression set (<10%), −60…+200 °C | ~3× EPDM | Backup for steel version if fins underperform |
| EPDM closed-cell foam | ⚠️ same limit | ⚠️ good UV but 20–40% set at high compression → loosens | cheap | Demoted: fine for a quick mock-up only |
| Neoprene foam | ⚠️ | ❌ worse UV than EPDM | cheap | No |

The three stacked fit mechanisms, in order of action:

1. **Fins** absorb the big spread (Ø32–46 mm) elastically.
2. **Closure adjustment** (±2.5 mm effective diameter via three tongue-detent depths on
   the hook joint, §6.4 — the v0.6 hinge is a single fixed-diameter rod with no slotted
   position, so the detents are the only preload knob that exists) tunes preload at
   install time and re-tightens years later if the fins relax.
3. **Shim sleeve** (included) clips over the fins for Ø27–32 mm skinny tubes.

**v1 print spec (housing):** PETG for the first print (easy), **ASA for the outdoor
unit** (UV-stable; PETG chalks and creeps in Texas sun). 4 mm walls / 6 perimeters, 40%
gyroid infill, brass heat-set inserts for every screw (printed threads don't survive
re-tightening), printed hinge knuckles with a stainless pin. The latch keeps its
**steel** receiver bushing and pin even in the printed housing — plastic there would let
someone pry the head out with a screwdriver. Obvious caveat, stated once: a plastic
housing is a functional model, not a security device; the steel shell is what makes the
housing itself attack-resistant.

### 6.3 Cable and spool

| Item | Spec |
|---|---|
| Cable | 4 mm 7×7 stainless wire rope, clear PVC jacket to Ø5 mm, 1.8 m on spool / ~1.5 m usable |
| Spool | Core Ø40 mm, flanges Ø85 mm, 26 mm between flanges → 1.8 m fits in ~2 layers |
| Return spring | Spiral power spring (constant-force preferred), 15 × 0.15 mm strip — the spring+spool unit from a heavy retractable dog leash or badge reel is a perfect donor for prototyping |
| Cable exit | Brass-lined grommet at bottom of pod, angled 30° down so the cable doesn't kink |
| Cable head | Hardened steel "mushroom": Ø10 mm head, ramped 45° nose, 3 mm-deep annular groove Ø7 mm behind the head |

Minimum bend: 4 mm 7×7 rope tolerates the Ø40 mm core (10× rule of thumb) — this is why
the core can't be smaller.

### 6.4 Latch + locking pin (the heart of it)

```
        cable head (mushroom)          hardened receiver bushing
              ══►  ╭──╮      ┌───────────────┐
   insert ─────────┤  ├──────►   ○ groove    │
              ══►  ╰──╯      │       │       │
                             │  [screw head] │  ← closure screw at the bore bottom:
                             └───────┼───────┘    covered by the cable head when locked
                                     │ Ø4 mm hardened pin, 3 mm engagement
                              ┌──────┴────┐
                              │ pin spring│  (locks: spring pushes pin into groove)
                              ├───────────┤
                              │ solenoid  │  (unlocks: pulls pin against spring)
                              └───────────┘
```

- **Insert (lock):** the 45° ramp on the head cams the pin back; pin snaps into the groove.
  Zero power. A weak ejector spring behind the head is compressed as it seats.
- **Remove (unlock):** solenoid pulls the pin 4 mm; ejector spring pops the head ~5 mm out
  so it can't instantly re-latch; spool retracts the cable.
- Pin = **the solenoid's own Ø6 plunger** (v0.3 change, see ASSEMBLY.md §3.1): a 45°
  ramp is filed on its nose, it runs in a Ø6.6 channel through the boss, and the
  solenoid's included return spring provides the locking preload. No separate pin,
  coupling, or spring seat. Cable-head groove widens to ≥6.5 mm to accept the Ø6 nose.
  Shear area is ample — the attack that matters is cutting the cable, not the pin.
- Fallback if the measured plunger force/geometry disappoints: the old separate Ø4
  hardened-pin design, which then needs its coupling fully drawn before printing.
- Receiver bushing: hardened steel insert so a screwdriver can't gouge the latch open.

**Male fitting trade study — square tang vs round head (resolved).** The original
concept was a square/rectangular male tang with an angled tip and a cross-hole: push it
in, the tip cams the pin back, the pin springs into the hole — the razor-scooter folding
latch. The alternative is the round mushroom head with a ring groove. Both use the exact
same cam-tip insert / spring-pin / solenoid-pull action; the shape is the only question.

| Criterion | Square tang + cross-hole | Round head + ring groove |
|---|---|---|
| Insertion | must be rotationally aligned — fiddly with a twisting retractable cable | works at any rotation, no aiming |
| Cable twist while locked | locked-in; attacker can use the cable as a torque lever on pin & socket, and normal use winds twist into the cable | head spins freely — twist self-relieves, torque never reaches the pin |
| Pin engagement | through-hole = double shear (stronger) | groove = single shear — but a Ø4 hardened pin in single shear (~11 kN) already exceeds the 4 mm cable's ~8–10 kN break strength, so the extra strength buys nothing; the cable is the fuse either way |
| Making the female side tight | square socket corners are hard to make crisp (printed or filed) → shim clearance | round bore is drilled/reamed in a hardened bushing → tight, round, shim-hostile |
| Sourcing the male part | easy DIY: flat bar + hacksaw + drill press | one lathe operation, or adapt an off-the-shelf hardened grooved pin |
| Commercial precedent | scooter folding latches (rigid hinge, orientation fixed by the frame — the one case where alignment is free) | AXA/ABUS plug-in chains (Ø10 hardened round pin into a frame lock), retractable cable-lock heads |

**Decision: round head with a square-flanked ring groove.** Cutting the groove with
square flanks (not a V) makes the pin seat against a flat wall exactly like the
cross-hole would — the groove is effectively the square design's hole, revolved 360° so
it's always aligned. The angled insertion tip from the original concept is retained
verbatim (that cam action is what makes no-power locking work). The square tang isn't
wasted: it's the recommended **bench mule** for Phase 0 — a hand-tools version to measure
real solenoid pull vs pin-spring force before any lathe work.

**Self-guarding closure screw.** The one fastener a consumer ever drives sits recessed at
the **bottom of the latch receiver bore** — the same hole the cable head locks into.
Consequences:

- **Cable locked → screw physically unreachable** (the hardened head fills the bore).
  The tongue-and-groove seam cannot be slid apart while the bike is locked, and unlocking
  requires an authorized tag. The housing's security is chained to the RFID auth — for
  *that one seam*.
- **Cable unlocked → screw exposed**, but then the bike wasn't locked anyway; the worst
  an attacker gets is the lock itself. Acceptable.
- The two flanges interlock with a **hooked tongue-and-groove joint** along the full
  110 mm seam (resists radial opening; can only disengage by sliding axially), and the
  bore screw is what blocks that axial slide. That's scoped to this one seam only: the
  hinge side is captive via the rod + screwed cap (no glue, no rivets in the v1 printed
  housing), and several *other* assembly seams — lid, hatch, spine cover, hinge cap — do
  carry ordinary external screws as of v0.6. §7 documents that exposure and its
  mitigations in full; "no screw heads anywhere on the outside except at the bore bottom"
  was true through v0.5 and is **not** true now.
- Geometry: receiver bore Ø11 mm × ~26 mm deep — cable head seats in the top ~12 mm,
  the closure screw drives down through it into the boss/flange stack below.
- **v0.6 closure stack** (corrects two defects that made the v0.5 screw non-functional).
  The hook flange stays at z25.2–28.2 but is capped at **y ≤ 6.5 mm** — a flange top that
  reaches further under the bore rises to z29.8+ and eats the bore floor the screw head
  needs to clamp against. A separate low insert **pad** at y6.5–13.0, z21.8–25.2 carries
  the fastener instead: a **short M4 brass heat-set (Ø5.6 × L3, VERIFY sourcing)** sits in
  a through-pocket installed from the pad's **top** face with the door open, flange-up, on
  the bench — insert mouth toward the screw, which is then driven from above, down the
  latch bore. The swept pockets that admit the flange and pad through the door's closing
  arc (flange prism + pad prism) peak at z26.27 in the bore column, leaving a **3.7 mm
  solid floor** under the z30 bore bottom — enough to actually clamp against. (D1: the
  v0.5 clearance hole ran through the wrong z-segment, pierced the bottom shell into the
  tube cavity, and never reached the door insert — the one consumer screw could not work
  at all, and a probe found only 2.48 of 142 mm³ left in that floor regardless. D2: the
  v0.5 insert pocket punched clean through the 3 mm flange (Ø5.6×6 cut into a 3 mm wall),
  so no insert could seat.) A 2.4×45° chamfer on the pad's lower −Y edge keeps material at
  r ≥ 23.4 mm against the Ø46 mm max-tube envelope. Screw: **M4×8 low-profile socket +
  washer**, reached with a long 2.5 mm hex key through the empty bore (deep + narrow also
  means common drivers can't get purchase if someone tries to gouge past a locked head).
  An M4×14 was sized on paper and rejected — it would hit tubes ≥Ø38 mm. The M4×8's tip
  reaches z22, clearing the Ø46 tube envelope by 1.2 mm and passing through the liner's
  swept transit window (§6.6 delta, `liner_right`) instead of gouging it. Clearance drill
  `closure_screw_d` 4.4→4.5 (standard M4 clearance).
- Fit-adjustment consequence: the ±preload adjustment for the one-size-fits-all clamp
  (§6.2) lives on the hook joint only — the tongue has **3 detent depths**, selected at
  install. (Through v0.5 this bullet also credited a slotted hinge-pin position for fine
  preload; the v0.6 hinge is a single fixed-diameter rod running in a finished bore with
  no axial or radial slack to tune, so that DOF is gone. The 3 tongue detents are the only
  preload adjustment that exists and remain unmodeled in CAD — TODO, same honest gap as
  before.)

### 6.5 Top pod internal layout & wiring plan — SUPERSEDED by the v0.4 split (§6.7)

*Kept for reference: this section describes the v0.3 layout with all electronics in the
top pod. v0.4 moves everything except the latch and reader to the bottom bay.*

Packing study with **verified part dimensions** (sources in BOM): PN532 42.7 × 40.4 × 4,
18650 holder 76 × 21 × 21, Nano 45 × 18, JF-0530B body 30 × 13 × 15 **plus its Ø6 × 58 mm
plunger** — the working solenoid train (body + plunger + pin coupling) is **~65 mm long**,
far too long to lie across a 55 mm pod, so it runs along the pod axis. Three zones that
must not overlap set the pod length — the PN532 needs a metal-free column above and below
it, the latch bore needs clear vertical depth, and the battery is a 76 mm brick →
**pod interior 150 × 55 mm, lid 34 mm above the shell crown.**

Because the pod floor is the curved shell (Ø62), depth grows from 34 mm at the centerline
to ~48 mm at the side walls — tall parts sit at the edges, and a printed half-width shelf
adds a second level over the solenoid strip.

```
 TOP VIEW, floor level (lid + shelf removed), X in mm along the frame axis
 X=0 (front / scan end)                                        X=150 (rear)
 ┌──────────────┬──────────────────────────────────────────────────┐
 │              │   18650 + holder (76×21×21)          [MT3608]    │ Y=32..53
 │   RF ZONE    │   X 55..131, along the side wall     [TP4056]▓───┼── USB-C port
 │  keep empty  ├○─────────────────────────────────────────────────┤ through rear wall
 │ (PN532 is on │bore  plunger→[solenoid body]  [ Arduino Nano ]   │ Y=4..22
 │ the lid above│Ø11   X 64..94 (tail trimmed)   X 100..145        │
 │  this void)  │X≈58                            (USB faces rear)  │
 └──────────────┴──────────────────────────────────────────────────┘
    X 0..48        "latch + drive strip" along Y≈14

 SHELF LEVEL (printed shelf at Z≈18, over the drive strip only, Y 0..26):
   perfboard X 60..100 — IRLZ44N, AO3401, flyback diode, 1000 µF cap, divider
 LID: PN532 under the plastic window (X 0..45), wake button + LEDs at X≈50
```

**Zone by zone:**

| Zone | Where | Contents & orientation |
|---|---|---|
| RF | X 0–48, full width | PN532 mounted to the **underside of the lid** (bosses), antenna up under the 2 mm plastic window. Nothing metal above or below — the void beneath stays empty except two signal runs hugging the floor edge. Battery steel can is 55+ mm away (the #1 read-range killer). Wake button + LEDs on the lid at X≈50 |
| Latch + drive strip | Y 4–22, X 48–145 | Receiver bore (Ø11 × 26 deep, vertical) at X≈58 Y≈14, over the closure flange so the bore-bottom screw clamps the halves (§6.4). Solenoid body at X 64–94 lying on the floor, plunger toward the bore (−X); pull-type: energize → plunger retracts +X, dragging the locking pin out of the bore wall. Plunger tail trimmed so the train ends ≈X 98. Nano at X 100–145, USB toward the rear wall for lid-off reflashing. Pin spring coaxial with the plunger; ejector spring under the bore floor |
| Battery side | Y 32–53, X 55–131 | 18650 holder along the side wall — the deep edge absorbs its 21 mm height. TP4056 stands vertically at the rear wall (X 140–150), **USB-C port through the rear end wall** under a rubber dust flap, 5 cm leads to the cell it charges. MT3608 beside it |
| Shelf | Z 18–30, Y 0–26, X 60–100 | Perfboard with both MOSFETs, flyback diode, 1000 µF reservoir cap, divider resistors — directly above the solenoid it drives (wire drop <30 mm through a shelf slot) |

**Why this orientation works:**

- Scan face at the front end = natural "tap here" target, maximally far from the battery.
- The solenoid train and the bore share one axis line (Y≈14) that sits directly over the
  closure flange — required by the self-guarding screw (§6.4).
- Every high-current run (battery → TP4056 → MT3608 → perfboard → solenoid) lives in the
  rear half; the RF end carries only 3 thin signal wires.
- No wiring leaves the top pod at all: the bottom spool pod is purely mechanical.

**Wiring plan (~15 conductors total):**

| Run | Wire | Route |
|---|---|---|
| Battery → TP4056 → MT3608 → perfboard 5 V bus | 22 AWG | rear corner cluster, 5–8 cm runs |
| Perfboard → solenoid | 22 AWG | straight drop through the shelf slot, <3 cm |
| Perfboard 5 V/GND → Nano | 26 AWG | 4 cm along the strip |
| Nano A4/A5 + D7 → PN532/P-FET | 28 AWG | 3-wire ribbon along the Y=0 floor channel |
| Lid parts (PN532, button, LEDs) → body | 28 AWG | one 15 cm service loop at the X≈50 hinge-side corner so the lid opens fully; JST-XH connector so it CAN unplug |

All of this is modeled in the CAD (`cad/bike_lock.scad`, v0.2), not just described:
clip-lip raceways on the floor (RF ribbon x4–54, power/solenoid run x60–100), a driver
tray bridging the Nano bay with wire notches and zip-tie holes, two battery saddles that
give the holder a level bed over the curved floor (zip-tie pass-unders included), and
mushroom-head strain-relief posts anchoring the lid's 15 cm service loop. Every off-board
connection gets a JST-XH plug so any module can be swapped without soldering.

**Fill check:** component volume ≈ 92 cm³ (battery+holder 34, latch block + solenoid train
20, PN532 + keep-out 15, Nano 10, boards 8, misc 5). Usable pod volume ≈ 195 cm³ after
subtracting the curved shell intrusion → **~47% fill, >30% reserved for wiring and
fingers** — comfortably inside the 70–75% max-fill rule of thumb for hand-assembled
enclosures.

### 6.6 v0.5 "spine + door" architecture (current) — the consumer-install redesign

**v0.4 had a fatal flaw found in assembly review: it could not be installed.** The pod
overhung the seam and the full-width bay blocked both the door's swing and the tube's
entry path. v0.5 is governed by three kinematic rules, now **machine-verified on every
CAD build** (`python bike_lock_cq.py --sweep`):

1. **Entry corridor** — the tube slides in from the left at axis height; no fixed
   material may exist in that swept slab (±23.5 mm). The pod becomes asymmetric (left
   wall at y −17, its fringe floating 0.6 mm above the closed door); the belt band and
   left fairing are gone.
2. **Door swing** — the door is a light arc panel carrying only its TPU liner half and
   the closure flange+lip; pod, bay, and drum all live right of y +7, outside the door's
   swept annulus. Verified: zero interference through 0–110° of opening.
3. **Slim drum** — spool axis turned 90° (along Y): a Ø68 × 32 wheel tucked low-right,
   cable 1.2 m × Ø4 (was 1.5 m — still loops a wheel + rack). The lock's lowest point
   rises from −121 to −94 mm; the spool cover faces outboard and is serviceable in place.

Consumer install: swing the door open, press onto the down tube, swing shut, drive ONE
hidden M4 down the latch bore. The latch line (bore, boss, solenoid, pedestal) sits at
y +10 — on the body's side of the seam, since the pod's left floor IS the closed door.
The door's flange reaches under the bore through a swept pocket (the pocket is the
union of the flange's positions through the closing arc, so engagement is rotational
and snag-free by construction).

**v0.6 delta (current):** layers onto the three kinematic rules above without changing
them. Hinge collapses to a **single Ø4.0 mm continuous rod** through both shell halves
(was two Ø3 mm pins + glued end plugs) — retention and thermal detail in §6.1/§6.8/§6.9.
The wire spine, sealed in v0.5, is now an **open lay-in raceway with a screwed cover**:
the roof over x23.5–32.5 is deleted, wires drop in instead of being fished blind, and a
curved cover plate seats on a rabbet ledge with a 0.5 mm shadow-gap reveal and 2× M3
self-tap screws (§6.8). The bay module is repacked: the LiPo now stands **on edge** along
the +Y wall instead of lying flat, because the flat-frame pocket and the TP4056 block
occupied the same floor footprint and the battery physically could not fit (D11); the
service hatch becomes a **component tray** (nesting pad, zip-anchor grid, diagonal Nano
mount) rather than a blank cover, since the floor beneath it is now a real service window
instead of the sealed floor the v0.5 hatch never actually served (D6). The liner keys onto
full-length **dovetail grooves** instead of friction+adhesive — no glue anywhere in the
assembly — and `liner_right` gains a swept **transit window** where the closure flange's
arc dips through its base ring (D10, found by the extended `--sweep` check). Two
verification parameters widened after that same extended sweep (moving set = door +
liner_left vs. every other part, not just body+bay+lid, which is what hid D10 in the first
place): entry-corridor margin `COR_Z` 23.5→**24.0 mm**, and the door-edge fringe float
0.6→**1.0 mm** (relief plane at z=32.0).

*(v0.4 "slim top" notes preserved below for reference — its layout concepts carried
into v0.5's bay brick.)*

### 6.6b v0.4 "slim top" architecture (superseded)

Owner direction: the top must be sleek; the bottom carries the mass and draws no
attention. Implemented in CAD v0.4 (`cad/bike_lock_cq.py`):

- **Top pod (126 × 56 × 25 mm outer — half the old height):** latch bore + solenoid
  (plunger-as-pin), PN532 under the lid window, wake button + LEDs. Nothing else.
- **Bottom bay** (one printed module around the spool drum, bolted by 4× M4 from inside
  the clamp bore): **front tunnel** = TP4056 + USB-C port (through the front wall, under
  a dust flap) + Nano + perfboard on a zip-anchor grid; **rear tunnel** = battery +
  MT3608. Both tunnels close with a shared bottom hatch part (printed twice).
- **Battery change: 103450 LiPo pouch (~2000 mAh, 34 × 50 × 10 mm, ~$6)** — a rigid
  76 mm 18650+holder cannot package beside the drum; anything crossing the drum's
  midsection hits the spool. Battery life drops from ~4–5 weeks to **~3.5–4 weeks**
  (§4.4 math scales linearly). Must be a cell **with protection PCB**, charged by the
  same protected TP4056.
- **Wiring paths (all printed in):** a hollow **wire spine** rib on the right shell side
  (x 96–112, void ~3.5 × 12 mm arc) carries ~11 conductors from the rear tunnel up
  through a slanted feed hole into the pod, under the belt line; a **corner duct**
  inside the bay (outside the drum ring, +Y top corner) links front↔rear tunnels for
  the 4 power wires; a short raceway inside the pod serves the PN532 ribbon.
- **Deleted in v0.4:** the cam-lock backstop (no wall tall enough in the slim pod — the
  USB power-bank unlock in §8 is the dead-battery path, as decided) and the separate
  battery saddles / driver tray / board pocket cartridges (their jobs moved into the bay).
- **Service note:** spool access now requires unbolting the bay (4 screws from the open
  clamp) — the cover can't slide out past the rear tunnel in place. Rare operation,
  accepted.

### 6.6c v0.7 delta — electronics as first-class placed bodies

Every BOM electronic now exists in the CAD as a dimensioned reference body (nominal
dims, VERIFY on arrival), placed in the assembly and covered by `--matrix`/`--gaps`:
packaging claims (solenoid body vs lid: >=1.0 mm; plunger tail TRIMMED to x98 vs the
wake button: >=1.0 mm; PN532 vs solenoid) are now machine-checked assertions, not
prose. Modeling them exposed two more v0.5 impossibilities, both fixed: (D13) the
TP4056 card slot pointed the USB-C at the floor - the board now lies FLAT in a rail
cradle at lane y=22 with the port through the wall (`usb_z` -46 -> -51.8); (D14) Nano
+ MT3608 + perfboard cannot fit the tray window co-planar (~2600 mm2 of boards vs
1195 mm2) - the tray is now a TWO-LEVEL cartridge: `nano_clamp (pod wall recess - superseded sled concept)` carries the Nano
diagonally (pins trimmed flush - the only way the stack fits), and a driver card held
a 40x29 perfboard on L-walls above it. **v0.7 final superseded all of this**: the Nano
edge-stands in the pod wall recess under `nano_clamp`, and ALL driver electronics sit
on a 42×10.7 card on the pedestal-cart’s −Y platform (v0.8.2 Option C: two Ø8 cart bosses at x66/x96, short M3 heat-sets — driver+solenoid+cart are one serviceable module),
<30 mm from the solenoid. The bay holds only the cell + TP4056; the spine carries
exactly 2 conductors. See BUILD.md §2.

### 6.7 RFID face

The PN532 antenna sits directly under a **plastic** window on the top face (13.56 MHz does
not pass through stainless). Keep all steel ≥10 mm clear of the antenna loop or read range
collapses; expect 1–3 cm range through 2 mm ABS. The wake button and LED sit beside the
window.

### 6.8 Tolerances & fastening plan (v0.6)

All numbers below are parameters in `cad/bike_lock_cq.py` (single source — read the
parameter block, not this table, when the two disagree). This section replaces the
per-joint tolerance guessing that shipped through v0.5: every screw in the assembly now
has a named pilot, clearance, and countersink pulled from one shared spec.

**Clearance & fit classes.** `--gaps` checks every placed pair against these bands with
`BRepExtrema` exact min-distance; `CONTACT_OK` is a whitelisted sentinel for faces meant
to touch (only true overlap fails the check, not zero gap).

| Class | Nominal gap | Where used | Notes |
|---|---|---|---|
| Clamped faying face | 0.00 mm (`CONTACT_OK`) | shell parting line, hatch-to-bay, spool cover-to-rabbet | modeled as touching by design; whitelisted so `--gaps` doesn't flag it |
| Static insert fit | 0.10–0.30 mm | heat-set pockets (M3/M2.5/M4-short), dovetail keys | press/friction fit, no relative motion once assembled |
| Hinge rod running fit | +0.2 mm diametral (finished) | Ø4.0 rod in the Ø4.2 `HINGE_BORE` | bore is drilled to finish size through the closed, clamped halves — FDM prints it undersized/drooped, so "finished" here means post-drill, not as-printed |
| Kinematic clearance | ≥0.4 mm | door-swing sweep, knuckle-to-knuckle gaps | closure engagement clearance `clr` kept at 0.5 (unchanged from v0.5) |
| Entry corridor margin (`COR_Z`) | 24.0 mm half-height (was 23.5) | tube entry slab | max tube Ø46 → ±23 mm, +1.0 mm margin |
| Door-edge fringe float | 1.0 mm (was 0.6) | pod left-fringe relief vs. the closed door's top edge | relief plane at z=32.0 |

**Pilot / clearance / countersink numbers, by thread:**

| Thread | Self-tap pilot | Through clearance | Countersink / counterbore | Insert pocket |
|---|---|---|---|---|
| M3 machine (into heat-set) | — | 3.4 mm | 90° CS, Ø6.4×1.8 (ISO 10642 flat head) | Ø4.1×6.5 brass heat-set (VERIFY insert brand dims) |
| M3 self-tap | 2.5 mm | 3.4 mm | CS Ø7.2×2.4 (ISO 7050 flat head — VERIFY 80°/90° head angle) | — |
| M4 machine/self-tap | 3.3 mm | 4.5 mm | pan-head counterbore Ø8.6×4.35 (head fully sub-flush of the bore) | — |
| M4-short (closure) | — | 4.5 mm | none — low-profile socket head | Ø5.7 through-pocket, L3 heat-set (VERIFY sourcing) |
| M2.5 machine (into heat-set) | — | 2.7 mm | none | Ø3.6×4.5 brass heat-set |
| Generic pad-boss pilot | 2.5 mm (was 2.6) | — | — | — |

**Fastening plan — every joint in the assembly:**

| Joint | Fastener | Pilot / clearance / CS | Driver access | Visible / hidden | Flush treatment |
|---|---|---|---|---|---|
| Closure (consumer screw) | M4×8 low-profile socket + washer ×1, into short M4 heat-set | clr 4.5 through boss; insert Ø5.7 through-pocket | long 2.5 mm hex key, down the open latch bore | hidden — cable head covers it when locked | recessed at bore bottom |
| Bay module ×4 | M4×12 pan self-tap | pilot 3.3; clr 4.5; counterbore Ø8.6×4.35 | from inside the open clamp bore | hidden — clamp must be open | pan head fully sub-flush of the bore (fixes D5 — heads used to stand 1–2.5 mm proud into the liner zone) |
| Lid ×4 | M3×10 CS machine (ISO 10642), into M3 heat-set in body rim bosses | clr 3.4; CS Ø6.4×1.8 | external, straight down from the lid's top face | **visible — externally removable on the locked bike** | countersunk flush with the lid's crowned top face |
| Hatch ×2 | M3×10 CS machine (ISO 10642), into M3 heat-set in the TP4056 block + drum web | clr 3.4; CS Ø6.4×1.8 on the **external** face | external, from the bay module's underside | **visible — externally removable on the locked bike** | countersunk flush; fixes D6 (v0.5's counterbore was on the internal face, so heads stood proud outside) |
| Spool cover ×3 (90/210/330) | M3×10 CS self-tap | pilot 2.5 into the ring-wall annulus boss at r31.25 (~5.5 mm engagement, fixes D4); clr 3.4; CS Ø7.2×2.4 | external, from the +Y outboard face | visible | outer face reads flat — CS depth absorbed by an underside pad nesting in a rabbet-floor relief pocket, not a dish in the visible face |
| Spine cover ×2 | M3×10 CS self-tap | pilot 2.5 into raceway end walls; clr 3.4; CS Ø7.2×2.4 | external, from the outer skin | **visible — externally removable on the locked bike** | countersunk flush |
| Hinge cap ×1 | M3×10 CS self-tap | pilot 2.5 into the shell end face; clr 3.4; CS Ø7.2×2.4 | external, rear end face | **visible — externally removable on the locked bike; removing it frees the hinge rod (§7)** | countersunk flush |
| Pedestal pads ×2 | M3×10 pan self-tap | clr ~3.4 through the base pads; driver access bored Ø6.5 through the tower | through the tower access holes, before the solenoid is mounted | hidden — heads covered once the solenoid body seats | none (pan head, buried) |
| Solenoid mount ×2 | M2.5×8 machine, into M2.5 heat-set in the tower top | clr 2.7; insert Ø3.6×4.5 | top-down into the tower, before the solenoid covers its own screws | hidden once seated | none — cyclic load joint, no CS; a captured-nut scheme was tried and rejected (no nut-insertion path once pads moved to 76/86) |
| PN532 mount ×4 | M2.5×8 **nylon** machine, self-tapping into printed drop-bosses (no insert — antenna wraps the board perimeter, no metal at the edge) | pilot 1.05, blind 2.6 mm deep, boss dropped 1.5 mm from the pocket ceiling | from inside the lid, before the lid seats on the body | hidden once assembled | none |

Deleted from the BOM: the Ø3 mm hinge pins, the glued end plugs, and an M4×14 closure
screw that was sized and rejected on paper (hits tubes ≥Ø38 mm — never buy it). Hinge rod
stock is Ø6 mm 303 stainless bar × 165 mm — not a fastener, listed here for BOM
completeness; the turning operation is in §6.9.

### 6.9 DFM & CNC path

Per-part machinability for the steel-shell / production phase (§6.2, §10 Phase 2). None
of this blocks the v1 printed build — it's forward-looking so the CAD doesn't need a
second redesign when the shell moves to metal.

| Part | Verdict | Setups | Notes |
|---|---|---|---|
| body | 3-axis, plus a 4th-axis feature | 4 (+ rotary) | see below |
| door | 3-axis, plus a 4th-axis feature | 3 (+ rotary) | see below |
| bay_module | 3-axis | 4 | top, bottom, +Y outboard face, and the front (−X) wall each carry features that can't share one fixture orientation |
| bay_hatch | 3-axis | 1 | flat plate — tray pad, 2× CS, zip-anchor grid all reachable from one face; through-holes carry the far-side features |
| pedestal_cart | 3-axis | 1 | every hole (pad clearances, insert pockets, driver-access bores, boss scallop) runs along Z — one top-down setup |
| lid | 3-axis | 1 | window pocket, PN532 bosses, button/LED holes, and the 4× CS all sit within reach of a single blank held once |
| spool_cover | lathe + secondary drill | turn, then drill/mill | disc + hub + hubcap dish are rotationally symmetric — turn those; the 3× M3 holes at 90/210/330 break symmetry and need a secondary drilling op (live-tooling lathe or a simple jig) |
| hinge_rod | lathe, one op | 1 | Ø6 303 stainless bar → integral Ø6×1.6 head, R0.5 head fillet, 0.4×45° head chamfer, R2.2 domed tail, trimmed at dry-fit. Center-drill the tail and support it on a tailstock live center — this is a 35:1 slender turn and **will chatter unsupported** |
| hinge_cap | 3-axis | 1 | disc + ear + bridge, one blind pocket, one through-hole, one CS — all from the same face |
| spine_cover | 3-axis | 1 | curved plate cut from the outside face; 2× through-hole + CS on the arc midline |
| liner_right / liner_left / shim | stays printed or molded | — | TPU 95A — not a metal-era part; injection/compression molding is the production path if volume ever justifies a tool, CNC doesn't apply to a flexible finned part |

**Body/door — the 3 changes that get them (mostly) to 3-axis, and the one feature that
doesn't:**

1. **Hinge bore** is now one straight Ø4.2 finished bore through every knuckle and
   standoff (was two blind Ø3.2 channels + stepped pockets for the glued end plugs) — a
   single axial drill pass replaces stepped/blind tooling.
2. **Dovetail liner groove**: one straight full-length axial pass per shell half, cut
   with a form tool from the end face — no plunge, no pocket-clearing.
3. **Bay-mount and spine-cover holes** sit on constant radial lines (`bay_screw_y`, the
   raceway end-wall plane) rather than scattered depths, so the through-holes and
   counterbores on each line come off one fixture angle instead of several.

The exception: the **closure sweep pockets** (flange prism + pad prism — the volume the
door's flange and pad sweep through as it swings shut, §6.4) are literal swept forms about
the hinge axis, cut into both `body` and `door`/`liner_right`. A rigid 3-axis mill can't
cut a true swept pocket in one pass; it needs a **4th axis** (rotary about the hinge axis)
to index the cut through the arc — for the steel version that rotary axis is physically
the **piano-hinge direction**, so it's a natural addition rather than a special fixture.
FDM sidesteps this entirely (the sweep is baked into the printed geometry).

**Tube-stock strategy (body/door):** both parts are fundamentally a cylindrical shell
(`outer_cyl()` cut by `tube_bore()`, then split at the parting plane), so the steel
version should start from **tube stock** close to the finished OD (Ø57 mm steel target,
§6.1) and wall (1.5 mm), not a solid round bar turned down. Roughing a solid bar to a
1.5 mm wall removes the overwhelming majority of the stock as chips; starting from tube
removes most of that roughing volume before the half-shell split, pod, and boss features
are even touched.

**Taps replace self-taps once the shell is metal.** The pilot-hole parameter set (§6.8)
was sized for FDM self-tapping in plastic, but two of the three thread sizes already carry
over as standard tap-drill sizes — no redesign needed, just add a tapping pass instead of
relying on the screw to cut its own thread:

| Thread | Tap drill (metal) | Matches the existing plastic self-tap pilot? |
|---|---|---|
| M2.5 × 0.45 | 2.05 mm | No — the two M2.5 joints (solenoid, PN532) use heat-sets or a nylon self-tap in the printed version, not a bare pilot; size the metal tap drill fresh |
| M3 × 0.5 | 2.5 mm | Yes — `M3_PILOT = 2.5` already matches the standard M3 tap drill |
| M4 × 0.7 | 3.3 mm | Yes — `M4_PILOT = 3.3` already matches the standard M4 tap drill |

**Dovetail groove:** slide-in from the end face. `dovetail_groove()` is a constant
cross-section extrusion the full 146 mm length, so it's cut with a single straight pass of
a dovetail form tool started at the front face — same operation on a manual or CNC mill,
no plunge-milling, no multi-axis motion.

---

## 7. Security analysis — honest version

| Attack | Resistance | Mitigation / status |
|---|---|---|
| Bolt-cut the 4 mm cable | ❌ seconds | **This is the real limit of any cable lock.** 4 mm is a deterrent (opportunists, café stops), not U-lock security. Going to 6 mm cable roughly doubles cut resistance but grows the spool pod to ~Ø120 mm. ⚠️ Decide after seeing the v1 size on a real bike. |
| Unscrew the housing from the frame | ⚠️ partially, while locked | **The self-guarding closure screw (§6.4) still holds — but "every other seam is captive" is no longer true, and this row is rewritten for v0.6 honesty.** The tongue-and-groove seam itself can't be slid apart while the cable head covers its screw. Four *other* joints, though, are ordinary external screws reachable on the locked bike without unlocking anything: the **hatch** (2× M3, bay underside), the **spine cover** (2× M3, over the wire raceway), the **hinge cap** (1× M3, rear end face), and the **lid** (4× M3, top face) — full spec in §6.8. Consequences: removing the hatch or spine cover exposes the solenoid's bare drive leads, which run off the regulated 5 V rail — with those two leads and any 5 V source an attacker can fire the solenoid directly, a non-destructive unlock that never touches the RFID. Removing the hinge cap frees the rod's axial float and lets the single hinge rod slide out the front; the two shell halves then come apart, but the **bike stays cable-tethered** — the cable head is still latched in the boss/receiver, so the housing detaches while the lock itself doesn't release. The lid is the fourth instance of the same class: v0.5's lid screws had no working pilots (D3), so the lid was never really a fastened joint; v0.6 gives it real M3 pilots in the body rim (§6.8), which means removing it now gives direct mechanical access to the top of the latch boss and the solenoid's own plunger — the same "external screw → internal mechanism access" trade-off as the hatch/spine-cover lead exposure, just reaching the pin instead of the leads. **Owner-accepted for the prototype phase** ("reasonable outward screws OK for now" — a schedule trade-off being logged, not a security requirement being waived). Production mitigation list, not yet built: one-way/security screw heads or staking on lid, hatch, spine cover, and hinge cap; potted or sleeved solenoid drive leads so they can't be tapped from outside; hidden lid fastening (already roadmapped independently of this finding). |
| Cut the printed (plastic) housing | ❌ v1 only | Inherent to the printed model — it's a functional prototype, not a security device (§6.2). The steel shell closes this. |
| Clone a fob UID | ⚠️ | Real but low-likelihood for a bike; fixed by v2 challenge–response (§5). |
| Drain/wait out the battery | depends | See §8 — this is why fail-open is dangerous. |
| Smash the electronics pod | ⚠️ | Breaking the solenoid/pin area could jam it *locked*, not open it (pin is spring-into-lock). Acceptable failure direction. |

Positioning: this is a **convenience lock** — always on the bike, zero-effort, good enough
for short stops and low-theft areas, and a great engineering project. It should be honest
about not replacing a U-lock for overnight street parking.

---

## 8. Dead-battery behavior (RESOLVED: fail-secure + USB-C escape hatch)

**Decision: the lock stays locked when the battery dies (fail-secure), and the USB-C
charge port doubles as an emergency power input** — plug any phone power bank into the
port and the whole system runs immediately, even with a stone-dead cell: wake, tap,
unlock. No waiting for the battery to take charge.

Implementation note for the electronics build: the TP4056 module's OUT+/OUT− terminals
(not the battery terminals) must feed the MT3608, so the load is powered from USB
whenever USB is present. That's the standard wiring for the protected TP4056 board
anyway — just don't tap the system rail directly off the cell.

*(v0.4 update: the cam-lock backstop was deleted — the slim top has no wall tall enough
for its barrel. Bench-test the electronics thoroughly before first on-bike use; the USB
power-bank unlock is the sole dead-battery path, which is the accepted design.)*

The earlier idea (unlock on battery death) was rejected for the record — one problem of
security and one of physics:

1. **Security:** if a dead battery unlocks the cable, a thief doesn't need bolt cutters —
   they wait, or chill the pack, or just come back in a month. The lock's security would
   equal its battery life.
2. **Physics:** the natural solenoid arrangement (energize-to-unlock, spring-to-lock) is
   inherently **fail-secure** — no power means the pin stays in. Making it fail-open
   requires either holding the solenoid energized the whole time the bike is locked
   (battery dies in hours, not weeks) or a bistable/motorized latch plus supervisory
   circuitry that fires a "last gasp" unlock as voltage collapses — more parts, more cost,
   and it *still* unlocks your bike in public when it triggers.

(The cam-lock backstop adds a keyway, which is itself a pickable attack surface — an
accepted v1 trade-off while the electronics prove themselves, and the reason it's slated
for deletion rather than kept forever.)

---

## 9. Open questions

None — every design decision to date is resolved. New questions get added here as
prototyping surfaces them.

*Resolved:* one-size-fits-all fit strategy → finned TPU liner + closure detents + shim
sleeve (§6.2). First housing is 3D printed → print spec in §6.2. Housing tamper
resistance → self-guarding closure screw at the bottom of the latch bore (§6.4). Male
fitting shape → round head with square-flanked ring groove; square tang kept as the
Phase-0 bench mule (§6.4 trade study). Dead-battery
behavior → fail-secure + USB-C power-bank escape hatch + v1 hidden cam-lock backstop (§8).
Cable gauge → 4 mm (spool pod stays Ø95). Owner's down tube confirmed inside the
Ø32–46 mm core range. TPU printing available → finned liner as specced, no silicone
fallback needed. Aero/oval Ø50 mm+ tubes confirmed out of scope for v1. Phone plan →
owner has an iPhone: sticker + fobs permanent, Android HCE app dropped from the roadmap.

## 10. Build plan

| Phase | Goal | Cost |
|---|---|---|
| 0 — Breadboard | Nano + PN532 + MOSFET + solenoid on a bench PSU; firmware v1 working end-to-end | ~$25 electronics |
| 1 — **Printed v1** (the first real model) | ASA/PETG clamshell + TPU finned liner + donor-leash spool + latch; whole system living on the actual bike; measure solenoid force vs pin spring; fit-test the liner on every bike we can find (target: 5+ different tubes across Ø32–46 mm) | ~$15 filament + hardware |
| 2 — Steel housing | 304 shell (rolled sheet or machined), hardened bushing + pin, final cable; liner carries over unchanged | TBD, ~$40–80 depending on fabrication access (TAMU shop?) |
| 3 — v2 electronics | Pro Mini 3.3 V swap (months of battery) | ~$10 |

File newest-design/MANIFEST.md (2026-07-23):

# Release v0.8.3 — manifest

This folder holds the **current frozen STEP set** (files labeled `_v083`). It carries the
whole v0.8 lineage — the sections below record each sub-iteration (v0.8 → v0.8.1 → v0.8.2 →
v0.8.3); older sub-states are recoverable from git history. Per the repo reorg, releases are
**STEP-only** (per-part `placed/` + assembly + combined); STL/renders/doc-snapshots are
regenerable from the source at this tag.

## v0.8.3c — pod-corner "swooping horn" root-cause fix (owner-flagged)

The knife-edge cusps at the pod's top corners were root-caused past the rebate itself: the
**PN532 board's square corners sat only 0.3 mm from the pod's OUTER corner surface** — no
relief could clear them without carving the corner wall to a blade. Systemic fix, all
machine-verified (gaps 0/292 · support 0/27 · matrix 0 · sweep 0.00):
- **Board shifted +3 mm in X** (`pn532_x` 2→5; lid window/bezel/bosses/NFC ring follow the
  one parameter) so its corners fit inside a uniform-wall boundary with 0.4 clearance.
- **Rebate contour rebuilt as an inward offset of the OUTER plan** (−1.3/side, corner arcs
  concentric with the pod's outer corners) → the remaining wall is a uniform 1.3 mm by
  construction, corners included. It also now stops at the z53 seat plane (the board top
  dropped to z52.7 via `PN532_BOSS_DROP` 1.5→2.1), so the seat rim stays full thickness.
- **Front lid screws moved x50→x54** — the board shift put the board edge and the lid's
  drop-bosses into the old rim-boss columns (gate-caught); at x54 everything clears ≥1 mm.

## v0.8.3b — pod-rim visual-flow fix (owner-flagged divots)

The PN532 wall reliefs were FIVE separate stepped box cuts whose raw terminations read as
divots gouged out of the top-wall corners. Replaced with **one continuous board-seat
rebate** following the pod interior's own rounded contour (+1.8/side, r4 corners for the
board's square-corner clearance), terminating at the x=50 lid-boss centerlines so the step
ends are swallowed by the boss cylinders. Same function (admits the 41 mm board), now reads
as an intentional ledge. Re-gated: gaps 0/292 · support 0/27 · matrix 0. STEP set refreshed
in place (`_v083` labels kept).

## v0.8.3 — environmental + DFM hardening (hard critique pass)

Multi-domain critique (manufacturability / water ingress / power), every finding either
fixed in CAD and machine-verified, or resolved in the docs:

**Water** (nothing was addressed before this pass — full table in DESIGN.md §4.5):
- **Latch-bore weep** (Ø2.2, offset from the screw axis): the Ø11×26 bore is open to the
  sky and pooled rain on the plunger — it now drains into the tube bore. Grease the plunger.
- **Drum-void weep** (Ø2.5 at the ring's lowest point): the snout enters at z≈−74 but the
  void bottoms at −90.5 — a 16 mm bucket under the donor spring, now drained.
- **New `usb_plug` printed TPU part**: squish-fit plug for the bay USB-C port (wheel-spray
  zone), flange + pull tab + lanyard hole.
- Documented seals (ASSEMBLY + BOM 30a-30c): EPDM foam tape on the lid rim, clear RTV over
  the LED domes, silicone grease on the plunger. Weeps must NOT be plugged.

**Manufacturability:**
- **Pedestal cart now prints dead flat**: the driver bosses hung 1 mm below the base plane
  (the part rocked on the plate). Base + platform + bosses now share one z32 bottom;
  DRV_SEAT rose to 36.3 (insert pocket keeps a 0.5 printed floor); the card gained an
  air gap under it (bonus drainage). Driver station nudged +0.4 y for wall clearance
  (gate-caught at 0.075 mm).
- **New `--dfm` mode**: report-only overhang scan of every printed part in its declared
  orientation (`DFM_ORIENT` = the documented orientation table, mirrored in BUILD.md §3b).
  Spool cover: print with a raft (its 3 nesting pads hold the disc 0.8 off the plate).

**Power (DESIGN.md §4.5):**
- **6 V-rail option documented as the first fallback**: MT3608 → 6.0 V, solenoid at full
  rated force (kills the 70%-at-5V compromise), Nano moves to VIN, PN532 feeds from the
  Nano 5 V pin through the existing P-FET gate. Zero new parts.
- **TP4056 load-sharing honesty**: charge with the lock asleep; clean load-share fix
  logged as a v2 item.

**Gate at freeze: gaps 0/292 · matrix 0 · sweep 0.00 mm³ · support 0/27 · dfm reviewed.**

---

# v0.8 lineage notes (original v0.8 manifest follows)

Snapshot of CAD v0.8 ("all-M3 heat-set fastening rebuild"), frozen from branch
`claude/file-contents-review-q89289` at the gate-green state. Every file in this
folder carries the `_v08` label. The live toolchain regenerates the unversioned
working copies under `cad/`; this folder is the fixed reference set.

**Gate at freeze: gaps 0 violations / 292 checks · matrix 0 clashing pairs @ 0.01 mm³ ·
door sweep 0.00 mm³ (0–110°) · entry corridor 0.00 mm³.**

## v0.8.2 structural pass — every load-bearing hole backed by solid, machine-audited

A new **`--support` gate** (collar-containment wall check) was built to catch the exact
failure the owner flagged: *"holes cut into thin walls / features stacked on top of each
other without connecting to solid."* It probes a required collar around all 27 load-bearing
threaded holes and reports the real backing wall. Initial run: **17 under-supported holes.**
All 17 are now resolved, re-verified against every gate (**gaps 0/292 · matrix 0 · sweep
0.00 mm³ · support 0/27**):

- **Bay bolts ×4** — the Ø9 boss was unioned *before* the cavity cut, so the cavity ate it
  to a crescent (~0 wall). Now unioned *after* → full 2.5 mm collar merging into the near wall.
- **Hatch ×2** — the Ø4 pocket pierced the 3 mm floor into the cavity. Relocated to clear
  spots (drum web / free floor lane) with floor→cavity backing pillars; a pad notch admits them.
- **Spool ×3** — buttress was clipped to the drum bore, starving 2 of 3. Now a full Ø9
  buttress behind the rabbet floor → 2.5 mm.
- **Pedestal pads ×2** — the pad overhangs the tube bore; switched to a **short M3** insert
  that sits above the bore, and moved 76/86 → **79/87** to clear the solenoid collar.
- **Solenoid @71** — its collar is capped ~1.35 mm on the boss side by the mandatory latch-boss
  clearance (documented; full ≥1.5 on the other three sides).
- **PN532 ×4** — the nylon pilot pierced the drafted RF window skin; now **blind** (grip is
  the full-wall boss), and the antenna-corner window skin stays unbroken.
- **Driver-card bosses ×2** *(design-level)* — were disconnected lumps the builder DROPPED
  (the card had **nothing to mount to**). **Final resolution (Option C): the driver card now
  rides the pedestal-cart's −Y platform**, not the body — the cart already carries the
  solenoid, so this puts the driver in a tiny flyback loop with the coil it drives, on a
  solid printed part (no body bracket), and makes driver+solenoid+cart one serviceable module
  with good RF separation from the lid antenna. The platform stays above the door-swing arc.
- **Closure insert** *(design-level)* — the door flap was being **erased by the tube bore**;
  it's now unioned after the bore (it lives in the liner's transit-window gap) and **both**
  liners carry a relief. Its −Y-bottom corner is at the Ø46-tube surface (chamfered for
  clearance, backed by the mounted tube in service; low-cycle set-once clamp).
- **Hinge tail-cap** *(carve-out)* — no boss can back it without breaking the door swing
  (rod + tube + OD + swing all converge), so it reverts to an **M3 self-tap** (its v0.7 spec)
  — a near-zero-load, single-assembly rod retainer.

Also: the lid top-cover perimeter is filleted (was a sharp arris) so the crowned face flows
into the sides. **Re-export the STEP/STL and renders from the v0.8.2 source before printing.**

## v0.8.1 refinement — heat-set holes tuned for a snug, clean fit

- **Pocket Ø 4.1 → 4.0, LOCKED** (owner decision + research: ruthex / Prusa/Voron / CNC
  Kitchen / Hiren size chart all spec ~Ø4.0 for M3 heat-sets with OD ~4.4–4.6, which is the
  typical generic-assortment M3). No test-fit needed to order. **One number** (`INS3_D` /
  `INS3S_D` in the CAD) sets every M3 pocket — change it once and the whole design re-cuts.
- **Lead-in relief at every pocket mouth** (Ø `INS3_D+1.4` × 1.0, plus a smaller one at the
  M2.5 solenoid pocket): gives the plastic the insert displaces somewhere to go, so the
  insert seats flush and clean instead of mushrooming. This relief is wider than any
  candidate bore (3.7–4.2), so tuning the pocket Ø never disturbs it.
- **`heatset_coupon` (new, NOT in the assembly)** — a graduated test bar: M3 holes at
  3.7/3.8/3.9/4.0/4.1/4.2 (front row) + M2.5 at 3.4/3.5 (back row), each with the same
  lead-in relief and a corner notch marking the small-Ø end. **Print it first** in the same
  material/settings, press one insert from your kit into each hole, and pick the Ø that
  grips snug + seats clean. Report that number and every pocket in the design locks to it.
  Exported at `heatset_coupon_v083.step` (STL regenerable from source).
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

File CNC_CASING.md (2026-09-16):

# CNC_CASING.md — the machined-casing redesign (concept + DFM contract)

Goal: a casing **designed for CNC from the first sketch** — fewer parts, simpler parts,
simpler assembly. The printed v0.8.3 remains the functional-prototype lineage; DESIGN §6.9
scored machining THAT geometry at 4 setups + a 4th-axis rotary, which is exactly what this
redesign deletes.
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

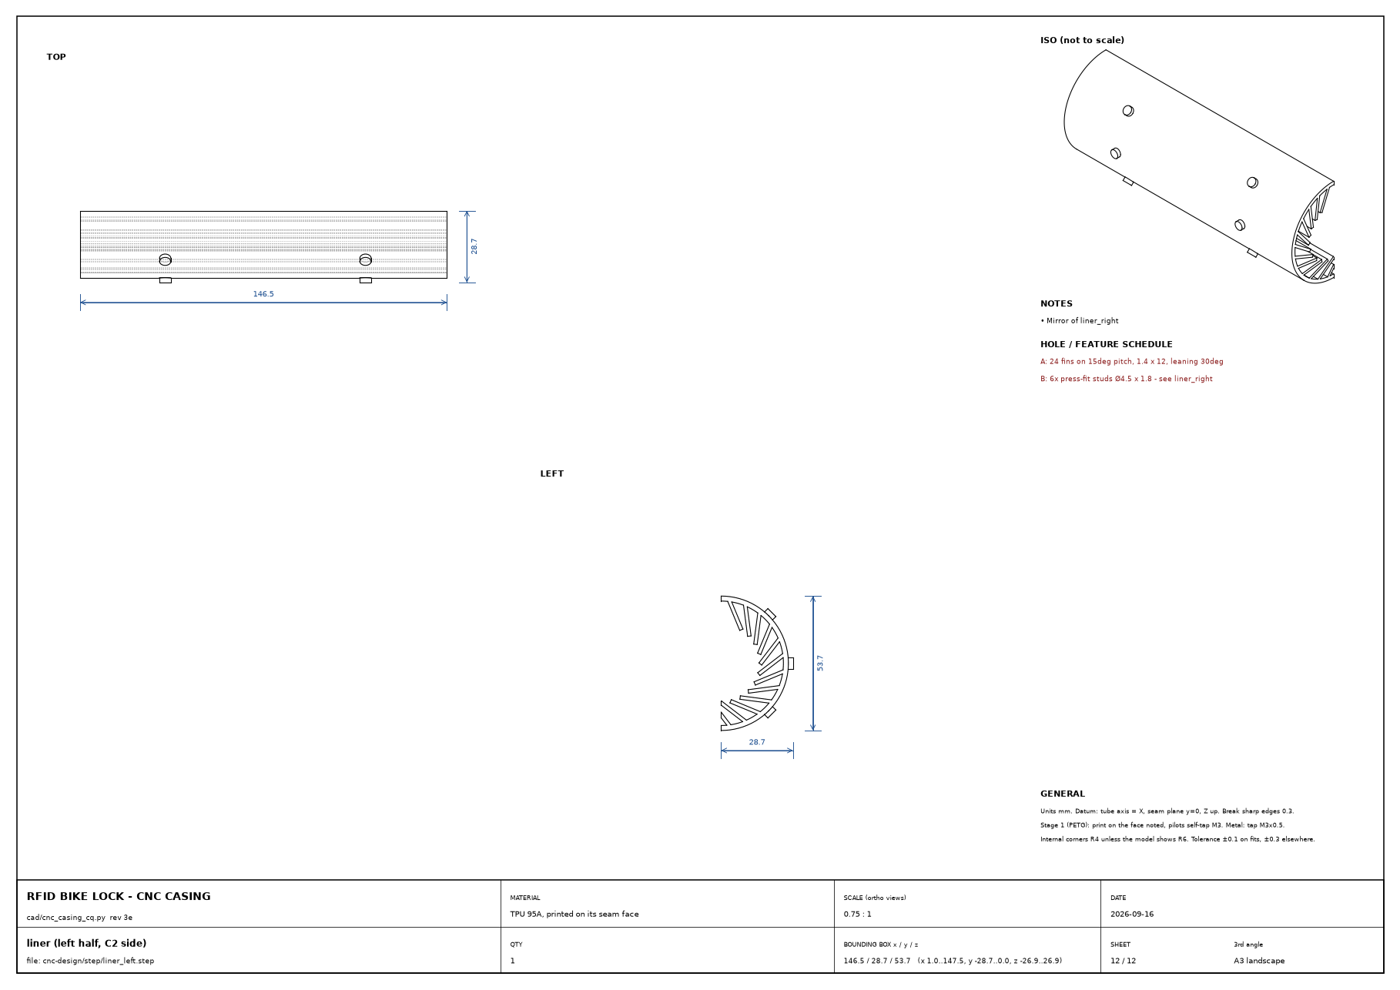
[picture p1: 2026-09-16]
cnc-design/drawings/12_liner_left.png

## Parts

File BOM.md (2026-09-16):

# Bill of Materials

Prices are typical AliExpress/Amazon hobby prices (mid-2026); buying the electronics as a
lot from AliExpress roughly halves the Amazon total but takes 2–4 weeks.

## Electronics (~$32)

| # | Part | Spec / example | Qty | Est. |
|---|---|---|---|---|
| 1 | Arduino Nano (clone, CH340) | 5 V/16 MHz | 1 | $4 |
| 2 | PN532 NFC module | Elechouse V3 style, set to I2C | 1 | $8 |
| 3 | Linear pull solenoid | JF-0530B **6 V** variant, ~20 Ω/300 mA, 5 N/10 mm; body 30×13×15 mm, plunger Ø6×58 mm | 1 | $4 |
| 4 | **103450 LiPo pouch, with protection PCB** | 2000 mAh, 34 × 50 × 10 mm (v0.4: the 18650 no longer packages in the bottom bay; stands on edge in v0.6 bay — 50×34 mm face vertical, clears the TP4056 block) | 1 | $6 |
| 5 | ~~18650 holder~~ | not needed in v0.4 — the LiPo sits in a printed frame in the bay | — | — |
| 6 | TP4056 charge board **with protection** (USB-C version) | has DW01 + FS8205 on board; 29 × 17.3 × 4.3 mm. ⚠️ **NOT a "2S/3S 8.4 V/12.6 V boost charger"** — those charge multi-cell packs and would drive our single 4.2 V cell to 8.4 V | 1 | $1.50 |
| 7 | MT3608 boost converter | set to 5.0 V; 36 × 17 mm | 1 | $1.50 |
| 8 | N-MOSFET (solenoid) | IRLZ44N (TO-220, logic-level) | 1 | $1 |
| 9 | P-MOSFET (PN532 power gate) | AO3401 / IRLML6402 (SOT-23 on breakout) | 1 | $0.50 |
| 10 | Flyback diode | 1N5819 Schottky | 1 | $0.20 |
| 11 | Reservoir capacitor | 1000 µF / 10 V electrolytic | 1 | $0.50 |
| 12 | Panel buttons | sealed momentary, panel-mount 12 mm — **2 off: green = wake/scan (D3), red = cancel/admin (D2)** | 2 | $2 |
| 12b | **Buzzer** | **ACTIVE** 12 mm piezo (self-oscillating, drive straight from D6). A passive one works with `tone()` — see firmware/README.md. Owner has both | 1 | $1 |
| 13 | LEDs + resistors | red + green 3 mm, 470 Ω ×2, 100 Ω, 100 kΩ ×3 | — | $1 |
| 14 | MIFARE Classic fobs | 13.56 MHz keychain fobs | 3 | $2 |
| 15 | NTAG213 stickers | for phone case "phone unlock" | 5 | $2 |
| 16 | Perfboard 4×6 cm, wire, heatshrink | CUT a **42×10.7 mm driver card** from the 40×60 board's long edge (v0.7 final: ALL driver electronics live on a card on two crown bosses in the pod, <30mm from the solenoid; the bay perf rack was deleted - the bay holds only the cell + TP4056). 1000 µF cap mounts **lying down** (Ø8×12.5 spec — order that case size). MT3608 mounts on the pedestal tower rails in the pod, NOT on the perfboard. Nano pins: **trim flush** after soldering (edge-stand recess policy) | — | $3 |

## Mechanical — Phase 1 printed v1 (~$40)

| # | Part | Spec | Qty | Est. |
|---|---|---|---|---|
| 17 | Housing filament | PETG for the first article; ASA for the unit that lives outdoors (UV), ~250 g | — | $6 |
| 17b | TPU 95A filament | finned liner + shim sleeve (DESIGN.md §6.2), ~50 g | — | $2 |
| 18 | Wire rope | 4 mm 7×7 stainless, PVC-coated, 1.5 m (1.2 m on the v0.5 slim drum) | 1 | $8 |
| 19 | Cable end stop / swage sleeves | 4 mm aluminum, crimp | 4 | $2 |
| 20 | Donor retractable reel | heavy-duty dog leash or badge reel (spring + spool) | 1 | $8 |
| 21 | Ejector spring | light compression, **Ø9 OD × 11 free, solid ≤ 4.5, ~0.5 N/mm** (CNC rev 3e — the old Ø9 × 15 goes solid in the 5.8 mm under the head): sits on the latch-bore floor around the closure screw head, compressed to 5.8 by the seated head; dropped in AFTER the consumer screw | 1 | $2 |
| 21b | **Latch cap** (rev 3e) | Ø8 × 10 steel cap, Ø10 × 2 rear flange, Ø6.1 × 8 bore over the HS-0730B plunger nose, Ø2 × 8 roll pin — the latch pin proper. **Lathe, Ø10 O1 drill rod, torch-hardened** (4140 pre-hard fallback). Printed prototype `cnc-design/stl/proto/proto_cap.stl` | 1 | $3 stock |
| 21c | **Return spring** (rev 3e) | **the solenoid's own front spring, cut to 10 mm free** (7.3 mm room at rest, 4.7 retracted); replace with Ø9 OD × 10, ~0.4 N/mm only if the factory wire is > 0.7 mm | 1 | — |
| 21d | **Mouth bushing** (rev 3e) | Ø10.3 ID × Ø14 OD × 10.55, **same O1 lathe session as the cap and head**, hardened; light press or Loctite 638 into the A1 boss, through the lid to its top face. Buy alternative: ANSI type-P press-fit drill bushing 13/32" (Ø10.32 ID, Ø15.9 OD) — needs `BOSS_D` 20 and `BTN2_Y` 14 in the model. Printed prototype `proto_bushing.stl` | 1 | $4 stock |
| 21e | **Cable head** (rev 3e) | Ø10 × ~22 hardened: 3 mm 45° cone, 3 mm land, 8.5 × Ø6.8 groove (square lower flank, 45° upper), Ø8 ferrule bored Ø4.2 for the swaged cable. Lathe, O1. Printed prototype `proto_cable_head.stl` (with a grip + cord hole) | 1 | $3 stock |
| 22 | Silicone sponge sheet — *only if TPU printing is unavailable* (fallback liner) | 10 mm, medium density | 1 | ($8) |
| — | **v0.8 FASTENER STANDARD** | Every threaded joint is an **M3 machine screw into an M3 brass heat-set** (super-refined printed prototype), with THREE carve-outs (v0.8.2): **solenoid** stays M2.5 (its own tabs are drilled M2.5); **PN532** stays M3 **nylon** into printed bosses (brass at the antenna corners kills read range); **hinge tail-cap** reverts to an **M3 self-tap** (its v0.7 spec) — the shell-end insert sits in a 4 mm wall pinched between the tube bore, the OD, the rod bore AND the door-swing envelope, so no heat-set collar is geometrically possible there (near-zero-load, single-assembly rod retainer). No self-tapping-into-plastic anywhere else. | — | — |
| 23a | Closure screw + insert | M3×10 countersunk machine ×1 + **short M3 heat-set (Ø4.0×L3.8)** ×1 — closure (v0.8: was M4; the shallow 3.4 mm pad needs the short insert) | 1 | $1.50 |
| 23b | Bay module screws + inserts | **M3×12 socket-cap ×4 + M3 brass heat-set ×4** — bay module (Ø6.0 counterbore, heads sub-flush inside the bore) | 4 + 4 | $1.50 |
| 23c | Lid + hatch screws + inserts | M3×10 countersunk machine (ISO 10642) ×6 + M3 brass heat-set ×6 — lid 4, hatch 2 (service joints) | 6 + 6 | $2 |
| 23d | Spool + spine + hinge-cap screws + inserts | M3×10 countersunk machine ×6 + M3 brass heat-set ×6 — spool 3 (ring-wall buttresses back the inserts), spine cover 2, hinge cap 1 (all flush machine-flat into inserts now) | 6 + 6 | $2 |
| 23e | Pedestal + nano-clamp + driver-card screws + inserts | M3 machine ×6 + M3 brass heat-set ×4 + **short M3 heat-set ×2** — pedestal pads 2 (into body pads), nano-clamp 2, driver card 2 (short inserts; **v0.8.2: the driver card now rides the pedestal-cart's -Y platform**, not the body — a tiny flyback loop with the solenoid the cart carries, and driver+solenoid+cart pull as one serviceable module) | 6 + 6 | $2 |
| 23f | Solenoid screws + inserts (**carve-out**) | M2.5×8 machine ×2 + M2.5 brass heat-set ×2 — solenoid (the JF-0530B's own tabs are M2.5; cyclic load) | 2 + 2 | $1 |
| 23g | PN532 screws (**carve-out**) | M3×8 **NYLON** machine ×4 — PN532 into printed bosses (RF keep-out; the antenna loop wraps the whole board perimeter — no brass/steel at the edges) | 4 | $1 |
| 23h | Hinge rod stock | Ø6 303 stainless bar, 165 mm. ONE lathe op: center-drill the far end and support it on the tailstock live center — a 140 mm Ø4 turn is 35:1 slenderness and **will chatter unsupported**; turn the Ø4.00 shank in light passes, leave the Ø6.0×1.6 head integral, R0.5 head fillet, 0.4×45° head chamfer, R2.2 domed tail; trim to length at dry-fit. Zero-lathe fallback: plain Ø4 ground rod or drill rod stock, cut to length, with a screwed cap at EACH end (no integral head, no lathe op) | 1 | $3 |
| 23i | ~~Cam lock backstop~~ | dropped in v0.4 (no wall tall enough in the slim pod); USB power-bank unlock is the dead-battery path | — | — |

| 23j | Reservoir cap size spec | order Ø8×12.5 mm 1000 µF/10 V explicitly — taller Ø10×16.8 variants exist and eat the shelf headroom | 1 | — |
| 30a | **EPDM foam tape** (v0.8.3 weatherproofing) | 1 mm × ~10 mm wide adhesive strip — lid-rim gasket under the 4 lid screws (+ optional hatch-pad lip strip). The reveal gap stays cosmetic; this is the water stop | 1 roll | $4 |
| 30b | **Clear RTV silicone** (v0.8.3) | small tube — pot the 2 LED domes into the lid holes; general seam sealer | 1 | $4 |
| 30c | **Silicone grease** (v0.8.3) | small tube — plunger + pin-channel anti-freeze film; also eases TPU liner install | 1 | $3 |
| 30d | **`usb_plug`** (v0.8.3, printed) | TPU 95A squish-fit plug for the bay USB-C port (wheel-spray zone) — print 2, tether one by the Ø2 lanyard hole. Uses grams of item 17b's TPU | 2 | — |

| 16b | JST-XH connector kit (2/3/4-pin) + crimps | pod-side connectorization; NOTE: factory-protected 103450 cells ship with JST-PH 2.0 pigtails - buy one PH pigtail or re-terminate | 1 kit | $4 |
| 23k | **Cable head, Phase 1** | (a) bench mule: steel flat bar ~12x6x60 square tang + cross-hole (hand tools, DESIGN 6.4) AND/OR (b) round mushroom head - ONE lathe op at the TAMU shop: O10 head, square-flanked ring groove to O6.6 x 3 deep, O5 stem swaged to the 4mm cable. The latch cannot lock without one of these; modeled as 89_mock_cable_head | 1 | $3 stock |

## Mechanical — Phase 2 steel housing (TBD, ~$40–80)

| # | Part | Spec | Qty |
|---|---|---|---|
| 24 | 304 stainless sheet | 1.5 mm, rolled to Ø55 mm shell | 1 |
| 25 | Stainless piano hinge | 30 mm segments | 2 |
| 26 | Hardened receiver bushing | drill bushing, Ø10 mm ID | 1 |
| 27 | Locking pin | not needed in v1 (solenoid plunger is the pin); steel version may revert to Ø4 drill blank | (1) |
| 28 | Cable head | machined, hardened mushroom w/ groove (shop job) | 1 |
| 29 | ABS/polycarbonate window | 2 mm, over PN532 antenna | 1 |

## Notes

- Item 6: make sure the TP4056 board is the **protected** variant (6 pins to battery side,
  two extra chips) — item 4's protection is then a second layer, which is fine.
- Item 3: buy 2–3 solenoids; clone JF-0530B force varies a lot and we need to match the
  pin spring to the real pull force at 3.5 V.
- Item 20: before buying springs (21), gut the donor reel — its spring, spool, and even
  the ratchet often cover items 21's ejector needs too.
- Item 17b: TPU prints best slow (~25 mm/s) on a direct-drive extruder; bowden printers
  can do 95A with care. If neither is available, fall back to item 22.

### VERIFY before buying / installing (v0.6)

- **v0.8.1 SNUG-FIT — LOCKED at Ø4.0 (M3):** the pockets ship at **M3 Ø4.0×6.5** (full) /
  Ø4.0×L3.8 (short) / **M2.5 Ø3.6×4.5**, each with a lead-in relief so displaced plastic
  doesn't mushroom. Ø4.0 is the research-backed standard for M3 heat-sets (ruthex, Prusa/
  Voron, CNC Kitchen, and the Hiren size chart all spec ~4.0 for M3 OD ~4.4–4.6, which is
  the typical generic-assortment M3). No test needed to order. The **`heatset_coupon`** part
  (Ø3.7–4.2 M3 + 3.4/3.5 M2.5) is now just an *optional* 2-minute sanity check — only worth
  printing if your kit's M3 feels tight to seat flush (a sign of a rarer ~5 mm-OD variant,
  where Ø4.1 would be the move).
- (legacy note, superseded by the coupon) Items 23a/23c/23f (inserts): confirm the actual
  brass heat-set brand/dims match the pockets — for the assortment kit, the M3 length just
  needs to be ≤6.5 (full pockets) or ≤3.8 (short: closure + driver-card), and M2.5 ≤4.5.
  There is no longer any M4 insert (all M3 in v0.8), so the old short-M4 sourcing risk is
  gone. Nylon PN532 screws (item 23g) self-tap into printed bosses and are single-use-ish,
  since re-tapping PETG/ASA repeatedly strips the pilot — keep a couple spare.
- Item 23d (ST flat-head self-tap screws — spool, spine cover, hinge cap): measure the
  actual screw's included head angle — clone self-tap flat heads ship as either 80° or
  90° — **before** countersinking; the printed countersink (Ø7.2×2.4) is cut for one
  angle and the wrong screw will either sit proud or bottom out before the head seats
  flush. (Item 23c's machine screws are a fixed 90° ISO 10642 countersink and don't need
  this check.)
- Item 3 (solenoid): before drilling the tower for the M2.5 attach inserts, measure the
  real JF-0530B's mounting-hole spacing against `sol_hole_dx` (24 mm in the CAD) — clone
  units vary, and the pedestal cart is a fast reprint but the inserts are not.
- Item 2 (PN532): confirm the board revision actually has the corner mounting holes
  (Ø3, 2.54 mm inset) before relying on the drop-bosses — some clones omit them, in which
  case fall back to the printed corner clips on the same bosses.
- Do **not** buy an M4×14 for the closure screw — it hits the tube envelope on any tube
  ≥Ø38 mm. The closure screw is M4×8 low-profile socket + washer (item 23a).

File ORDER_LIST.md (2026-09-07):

# ORDER_LIST.md — what to buy to finish the build (v0.8.3c, cross-referenced against owned inventory)

Priority = build order: P1 proves the electronics on the bench before anything prints in
final material. Links are Amazon search URLs (stable) or known listings — **Amazon blocks
automated price/stock checks, so confirm variant + price at checkout.** Prices ±20%.

## ✅ Already owned (RoomCleaner leftovers + kits) — do NOT re-buy

| Item | Source | Covers |
|---|---|---|
| Arduino Uno + breadboard + jumpers + resistors + 3mm LEDs + tactile buttons | ELEGOO UNO R3 Super Starter Kit | Entire breadboard phase; divider/gate resistors; lid LEDs |
| **RC522 RFID kit + MIFARE fobs** | Arduino RFID scanner kit | Full auth bring-up NOW (UID whitelist); maybe the final reader — see the pending range test |
| 12 V 6 A PSU + inline fuse + MP1584 bucks ×6 | RoomCleaner | Bench rig: 12 V → buck @ 6.0 V → solenoid pull tests |
| M3 button-head kit (640 pc, 6–30 mm + nuts/washers) | RoomCleaner | Bench/dry-fit fastening (finals need countersunk — P2) |
| PLA filament | owned | Fit-check prints before PETG |
| ESP32 ×3 | RoomCleaner | nothing now (v2 option) |

**Deferred pending test:** PN532 NFC module + NTAG213 tags (~$12) — only if the RC522's
read range through a 1.2 mm printed plate disappoints. Test before buying:
https://www.amazon.com/s?k=PN532+NFC+module+V3

---

## ✅ DELIVERED (orders confirmed 3–4 Sep 2026)

| Item | ASIN | Notes |
|---|---|---|
| Ferwooh MT3608 boost, 5-pack | B0D17PHDSD | as specced |
| **Heschen HS-0730B solenoid, DC 6 V 1 A, 5 N, 10 mm stroke** | B07MCBF7Z2 | ⚠️ **0730 frame, not the 0530 the CAD assumes** — see below |
| ALLECIN IRLZ44N, 10-pack | B0CBKH4XGL | as specced |
| **JLJLUP 103450 LiPo 2000 mAh, PH 2.0** | B0FH7H4Z7W | ⚠️ **52 mm long**, CAD tray is cut for 50 — see below |
| ALLECIN IRF4905 P-MOSFET, 10-pack | B0CBKH44K5 | the TO-220 alternative to the AO3401 reader gate — works, just bulkier |
| EEEEE 1N5819 Schottky, 150-pack | B0FC2CWKPL | as specced |

### ⚠️ Two fit checks the delivery created

**1. The solenoid is an HS-0730B, not an HS-0530B.** Good news on current: **1 A**, not the
3.4 A variant, so it runs off the 6 V rail (6 Ω coil; the MT3608's 2 A is enough, and the cell
sees ~1.9 A for 300 ms, right at its 1C rating — acceptable for a pulse, and a reason to try a
150 ms pulse before settling on 300). The problem is size: the CAD's cart is cut for a
**30 × 13 × 15 mm** body and an 0730 frame is typically **~34 × 20 mm**. At 20 mm wide, centred
on the plunger axis at y = −4, the body would span y −14 to +6 — and the box interior starts at
y = −11, so it would poke through the wall by 3 mm.

**Measure these five things on arrival and report them, then the cart gets refitted:**
body length · body width · body height · mounting-hole spacing · plunger diameter.

**2. The cell is 52 mm long**, not the 50 mm in the model (YTKavq's was 50). The battery tray
just shifts 2 mm toward −x; the reader deck above it is unaffected. Already logged.

---

## 🛒 STILL NEEDED

| # | Item | Why | Link | ~$ |
|---|---|---|---|---|
| 1 | **TP4056 charger, protected USB-C** | **the one real gap** — nothing else can charge the cell safely | https://www.amazon.com/s?k=HiLetgo+TP4056+Type-c+USB+charging+module+dual+protection | 6 |
| 2 | **1000 µF 10 V+, Ø8 × 12.5 case** | reservoir across the coil supply; taller cases don't fit the box | https://www.amazon.com/s?k=1000uf+16v+electrolytic+capacitor+8x12mm | 6 |
| 3 | **AMS1117-3.3 module** | clean 3.3 V for the RC522 — do not use the Nano's 3V3 pin | https://www.amazon.com/s?k=AMS1117-3.3+voltage+regulator+module | 7 |
| 4 | **22 AWG silicone wire**, red/black | the power runs | https://www.amazon.com/s?k=22awg+silicone+wire+red+black | 9 |
| 5 | **JST-XH kit + crimper** | the lid loop has to detach for reflashing | https://www.amazon.com/s?k=JST+XH+connector+kit+crimp+tool | 12 |

**≈ $40.** Later, for the build itself: PETG + TPU filament, M3 countersunk screws (your
button-head kit covers the ten inside-the-bore screws), Ø4 coated cable + swage sleeves, a
donor retractable reel, and a Ø5 × 36 steel dowel for the hinge pin.

### ▶ You can start building today
**Checkpoint 1 needs nothing you don't already have** — Nano, RC522, buttons, LEDs, buzzer,
breadboard. **Checkpoint 2** (solenoid driver) only wants the 1000 µF cap, and you can bench it
off the ELEGOO supply meanwhile. See `WIRING.md` §6.

### ✔ Already owned — do NOT re-buy
Arduino Nano · RC522 reader + fobs · active **and** passive buzzer · red + green LEDs ·
ELEGOO kit (breadboard, jumpers, resistors, tactile buttons, power module) · perfboard ·
heat-set inserts · soldering iron · **M3 button-head kit** — 5.7 mm across and 1.65 mm tall, so
they fit the Ø6.2 × 2.3 counterbores; only the lid and puck cover need countersunk.

### ✘ Not for this project
The **ACEIRMC 2S 8.4/12.6/16.8 V board** belongs to RoomCleaner's charging dock. It charges
multi-cell packs and would drive this lock's single 4.2 V cell to 8.4 V.

---

## P1 — Bench bring-up (order first; Checkpoint 1 needs only these + owned kit)

| # | Item | Spec / search term | Link | Qty | ~$ |
|---|---|---|---|---|---|
| 1 | **Solenoid** | JF-0530B pull-type, **6 V winding** (NOT 12/24 V) — VERIFY hole spacing + 13–16 mm width on arrival | https://www.amazon.com/s?k=JF-0530B+solenoid+6V+pull | 2 | 12 |
| 2 | **MT3608 boost** | 2 A adjustable boost module (your MP1584s are bucks — can't boost 3.7→5/6 V) | https://www.amazon.com/s?k=MT3608+boost+converter+module | 3–5 pk | 8 |
| 3 | **TP4056 USB-C** | protected version (has DW01 + FS8205) | https://www.amazon.com/s?k=TP4056+USB+C+charging+module+protection | 3+ pk | 7 |
| 4 | **LiPo cell** | **103450** pouch, 2000 mAh, **with protection PCB**, JST pigtail | https://www.amazon.com/s?k=103450+lipo+battery+2000mah+protected | 1 | 9 |
| 5 | **Logic-level MOSFETs + diode** | IRLZ44N (TO-220) ×5; AO3401 breakout or SOT-23 ×10; 1N5819 ×10 | https://www.amazon.com/s?k=IRLZ44N ; https://www.amazon.com/s?k=AO3401+mosfet ; https://www.amazon.com/s?k=1N5819+schottky | kits | 12 |
| 6 | **Reservoir cap** | 1000 µF / 10 V+ electrolytic, **Ø8 × 12.5 mm max** (taller variants don't fit) | https://www.amazon.com/s?k=1000uf+10v+electrolytic+capacitor+8mm | 5+ | 6 |
| 7 | **Perfboard** | 4 × 6 cm double-sided proto board (driver card cut from this) | https://www.amazon.com/s?k=4x6cm+double+sided+perfboard | pk | 6 |
| 8 | **Arduino Nano** | Nano clone (CH340), ×2 — Uno runs bring-up meanwhile; the pod fits a Nano | https://www.amazon.com/s?k=arduino+nano+ch340+3+pack | 2–3 | 12 |

## P2 — Printing + assembly tooling (order alongside P1)

| # | Item | Spec / search term | Link | Qty | ~$ |
|---|---|---|---|---|---|
| 9 | **Soldering iron + solder** | 60 W adjustable pen + 63/37 rosin core (not owned per RoomCleaner list; blocks inserts AND the driver card) | https://www.amazon.com/s?k=60w+adjustable+soldering+iron+kit | 1 | 20 |
| 10 | **M3 heat-set inserts** | Ø4.1(4.6 OD)×6.5 ~25× + **SHORT Ø4.0×L3.8** ~6× + M2.5 (Ø3.6×4.5) ×4 — ruthex/Hilitchi-style; print the coupon first | https://www.amazon.com/s?k=M3+brass+heat+set+insert+kit+3d+printing ; short: https://www.amazon.com/s?k=M3+heat+set+insert+short+3mm | kits | 14 |
| 11 | **Insert iron tips** | heat-set insert tip set for soldering irons | https://www.amazon.com/s?k=heat+set+insert+soldering+iron+tip | 1 | 9 |
| 12 | **PETG 1 kg** | HATCHBOX/OVERTURE PETG (you own only PLA) | https://www.amazon.com/HATCHBOX-3D-Filament-Dimensional-Accuracy/dp/B00J0ECR5I | 1 | 20 |
| 13 | **TPU 95A 1 kg** | OVERTURE TPU 95A 1.75 mm (liners, shim, usb_plug) | https://www.amazon.com/OVERTURE-Flexible-Printer-Filament-1-75mm/dp/B0991X92K8 | 1 | 22 |
| 14 | **M3 countersunk machine screws** | flat head ISO 10642 90°: M3×10 ×20 + M3×12 **socket cap** ×6 | https://www.amazon.com/s?k=M3+countersunk+flat+head+machine+screw+assortment ; https://www.amazon.com/s?k=M3x12+socket+head+cap+screw | kits | 10 |
| 15 | **M3 NYLON screws** | M3×8 nylon (PN532 — RF keep-out; skip if RC522 wins and I redesign its mount) | https://www.amazon.com/s?k=M3+nylon+screws+kit | kit | 6 |
| 16 | **M2.5 screws** | M2.5×8 machine (solenoid tabs) | https://www.amazon.com/s?k=M2.5x8+machine+screw | pk | 5 |

## P3 — Mechanical completion

| # | Item | Spec / search term | Link | Qty | ~$ |
|---|---|---|---|---|---|
| 17 | **Hinge rod stock** | Ø6 mm 303/304 stainless rod 300 mm (TAMU shop lathe job) — zero-lathe fallback: Ø4 mm drill rod + Ø4.2 drill bit | https://www.amazon.com/s?k=6mm+stainless+steel+rod+303 ; fallback https://www.amazon.com/s?k=4mm+drill+rod | 1 | 8 |
| 18 | **Drill bits** | Ø4.2 mm (hinge bore through clamped knuckles) + Ø6.5 mm (bore ream decision) | https://www.amazon.com/s?k=4.2mm+drill+bit ; https://www.amazon.com/s?k=6.5mm+drill+bit | 1 ea | 8 |
| 19 | **Retractable reel donor** | heavy retractable dog leash (small) or heavy-duty badge reel — donor spring+spool | https://www.amazon.com/s?k=heavy+duty+retractable+dog+leash+small | 1 | 12 |
| 20 | **Security cable** | **3 mm** 7×7 stainless wire rope, PVC coated to **4 mm**, 2 m + **swage sleeves** (CNC casing rev 3 spool is sized for Ø4; the printed v0.8 drum takes it too) | https://www.amazon.com/s?k=3mm+stainless+steel+wire+rope+pvc+coated+4mm ; https://www.amazon.com/s?k=aluminum+swage+sleeve+3mm | 1 | 12 |
| 21 | **Cable-head stock** | Phase-0 bench mule: steel flat bar ~3×20 mm (hardware store); round grooved head = TAMU lathe job later | https://www.amazon.com/s?k=steel+flat+bar+1%2F8+x+3%2F4 | 1 | 6 |
| 22 | **Spring assortment** | compression spring kit covering Ø9×~15 (ejector) — pin preload comes from the solenoid's own return spring | https://www.amazon.com/s?k=small+compression+spring+assortment+kit | kit | 9 |
| 23 | **JST connectors** | JST-XH 2/3/4-pin kit + one JST-PH 2.0 pigtail (protected 103450s ship PH) | https://www.amazon.com/s?k=JST+XH+connector+kit ; https://www.amazon.com/s?k=JST+PH+2.0+pigtail | kit | 10 |
| 24 | **Hookup wire** | 22 AWG silicone stranded red/black (RoomCleaner never bought it) | https://www.amazon.com/s?k=22awg+silicone+wire+red+black | 1 | 9 |

## P4 — Weatherproofing + finish (add to any later order)

| # | Item | Spec / search term | Link | Qty | ~$ |
|---|---|---|---|---|---|
| 25 | **Sealed wake button** | 12 mm waterproof momentary panel-mount (kit tactiles are bench-only) | https://www.amazon.com/s?k=12mm+waterproof+momentary+push+button | 2 | 8 |
| 26 | **EPDM foam tape** | 1 mm thick × ~10 mm wide adhesive strip (lid-rim gasket) | https://www.amazon.com/s?k=EPDM+foam+tape+1mm | 1 | 6 |
| 27 | **Clear RTV silicone** | small tube (LED potting + seams) | https://www.amazon.com/s?k=clear+RTV+silicone+sealant+small+tube | 1 | 5 |
| 28 | **Silicone grease** | small tube (plunger + pin channel anti-freeze film) | https://www.amazon.com/s?k=silicone+grease+dielectric+small | 1 | 4 |
| 29 | NTAG213 stickers (optional) | phone-case sticker keys — only alongside a PN532 | https://www.amazon.com/s?k=NTAG213+nfc+stickers | pk | 6 |

**New spend: ~$185–210** (P1 ≈ $72 · P2 ≈ $106 · P3 ≈ $76 · P4 ≈ $29, before the
deferred PN532). The RC522 kit + ELEGOO kit + bench PSU rig save roughly $70–90 vs
buying the BOM cold.

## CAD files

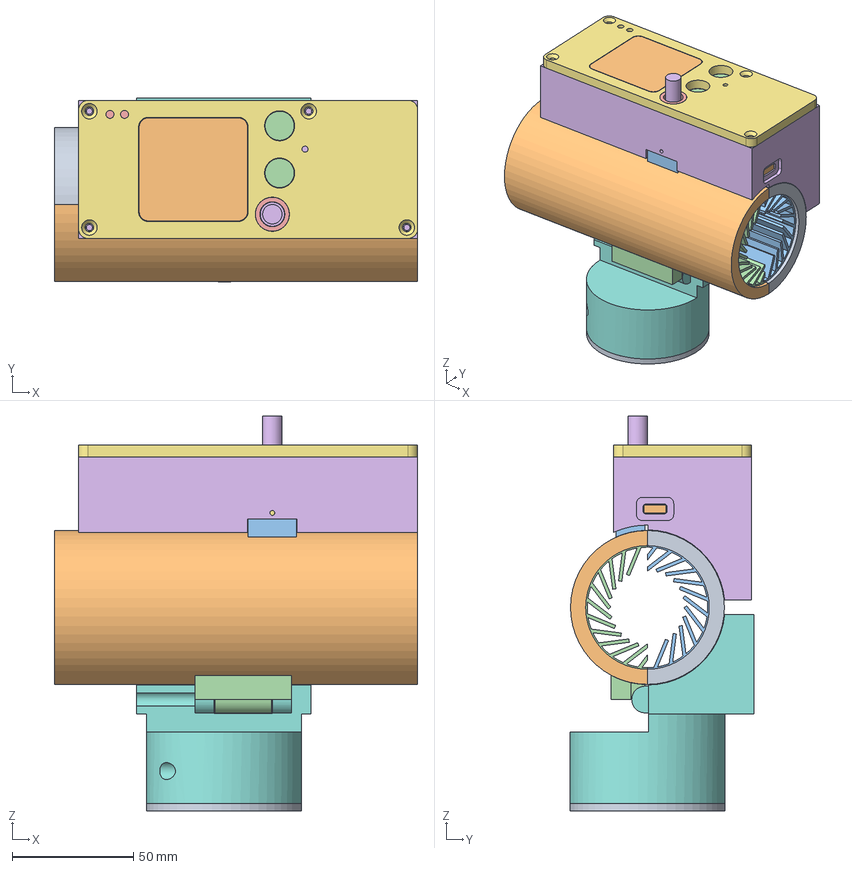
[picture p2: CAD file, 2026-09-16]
cnc-design/step/cnc_casing_assembly.step
150.0 x 76.0 x 163.0 mm
C1_chassis_half
C2_clamp_half
closure_block
hinge_block
hinge_pin
A1_top_box
A2_lid
A3_bottom_box
A4_cover_plate
A5_window_insert
liner_right
liner_left
ref_tray
ref_battery
ref_reader
ref_solenoid
ref_driver_card
ref_plunger
ref_cap
ref_ret_spring
ref_bushing
ref_head
ref_ejector
ref_closure_screw
ref_nano
ref_tp4056
ref_mt3608
ref_button_green
ref_button_red
ref_led_1
ref_led_2
ref_buzzer

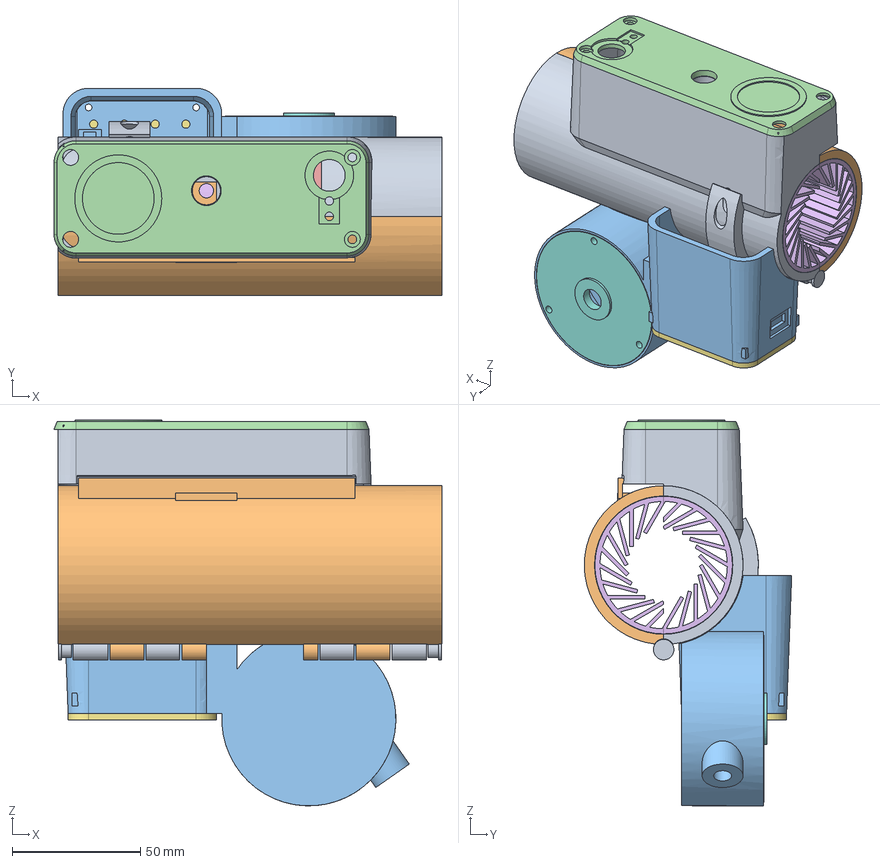
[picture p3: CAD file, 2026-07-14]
cad/step/bike_lock_assembly.step
151.5 x 81.0 x 150.6 mm
01_body
02_door
03_bay_module
04_lid
05_pedestal_cart
06_liner_right
07_liner_left
08_bay_hatch
09_spool_cover
10_end_plug_front
11_end_plug_rear

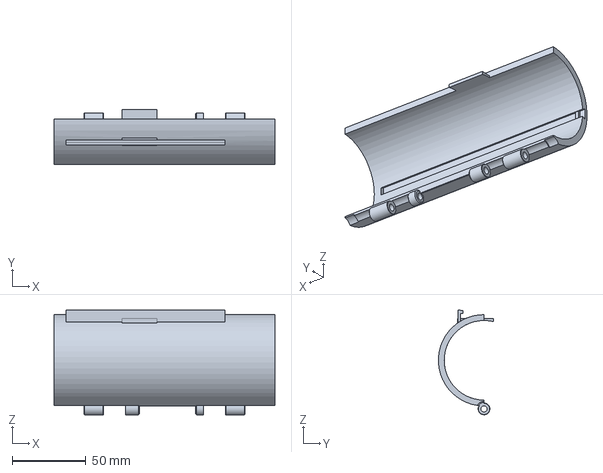
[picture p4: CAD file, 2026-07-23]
cad/step/door.step
150.0 x 37.5 x 71.0 mm

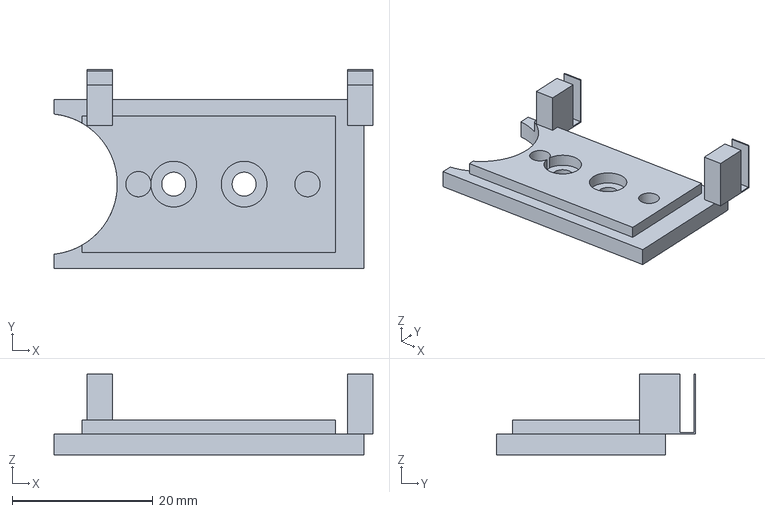
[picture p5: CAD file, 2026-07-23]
cad/step/placed/05_pedestal_cart.step
45.3 x 28.3 x 11.5 mm

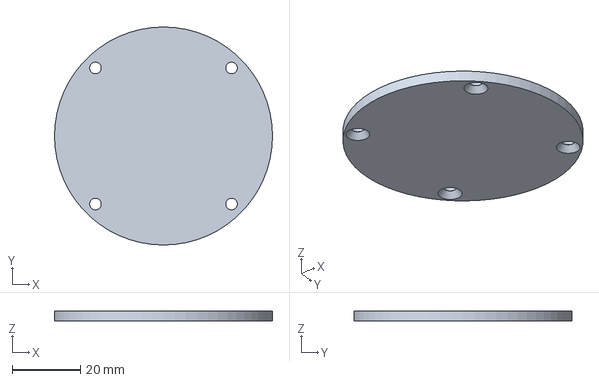
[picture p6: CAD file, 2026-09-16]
cnc-design/step/A4_cover_plate.step
64.0 x 64.0 x 3.00 mm

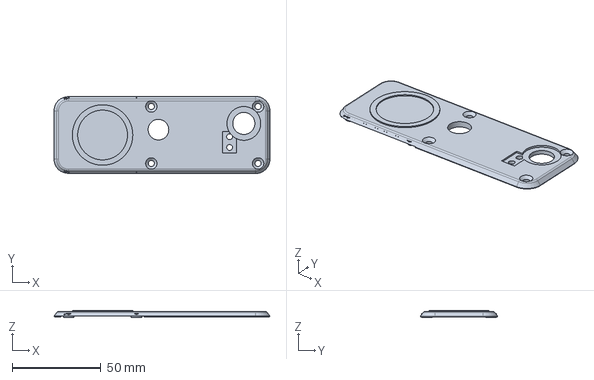
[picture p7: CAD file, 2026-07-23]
newest-design/placed/04_lid_v083.step
121.4 x 43.4 x 3.90 mm

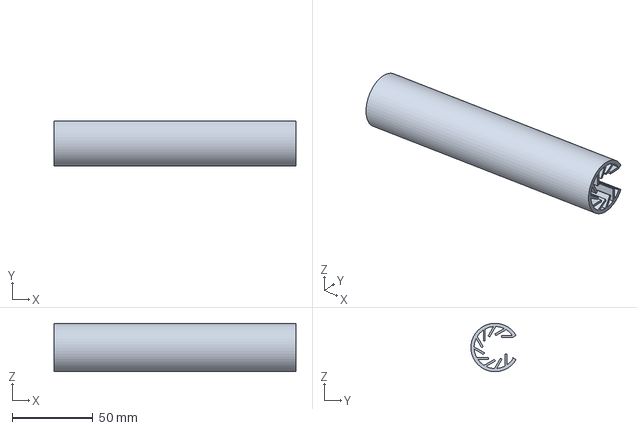
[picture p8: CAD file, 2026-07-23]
newest-design/shim_v083.step
150.0 x 28.0 x 30.0 mm

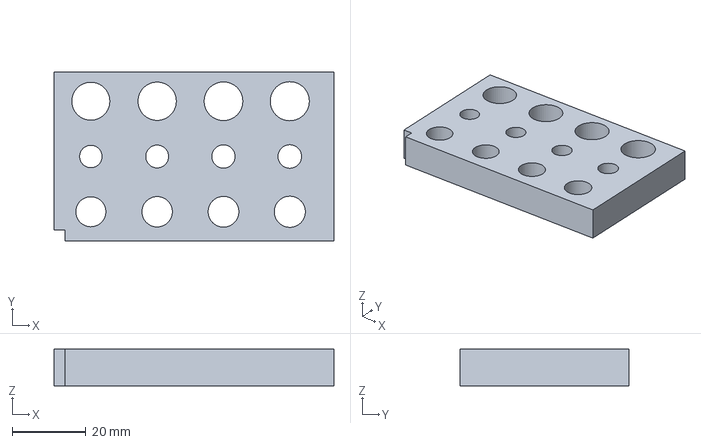
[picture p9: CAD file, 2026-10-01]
releases/rev3f/STEP/01_fit_coupons/01_latch_fit_coupon_PETG_rev3f.step
76.0 x 46.0 x 10.0 mm

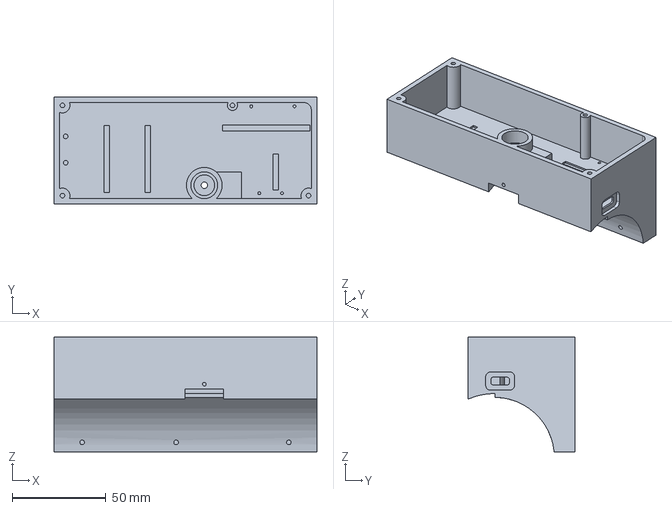
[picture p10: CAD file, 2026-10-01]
releases/rev3f/STEP/02_electronics_and_latch/03_A1_top_box_PETG_rev3f.step
140.0 x 57.0 x 61.0 mm

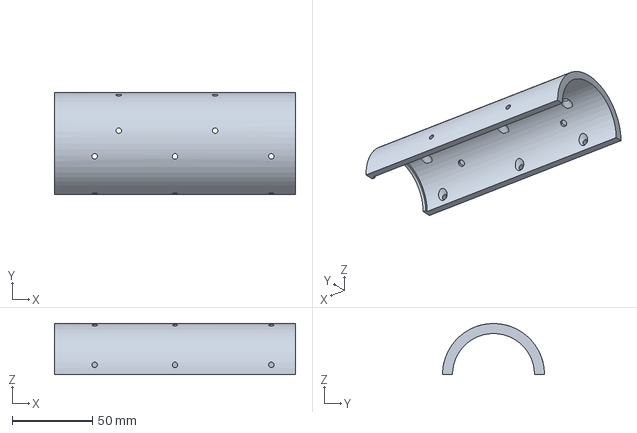
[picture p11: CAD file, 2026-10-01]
releases/rev3f/STEP/03_frame_optional/11_C1_chassis_half_PETG_rev3f.step
150.0 x 63.5 x 31.8 mm

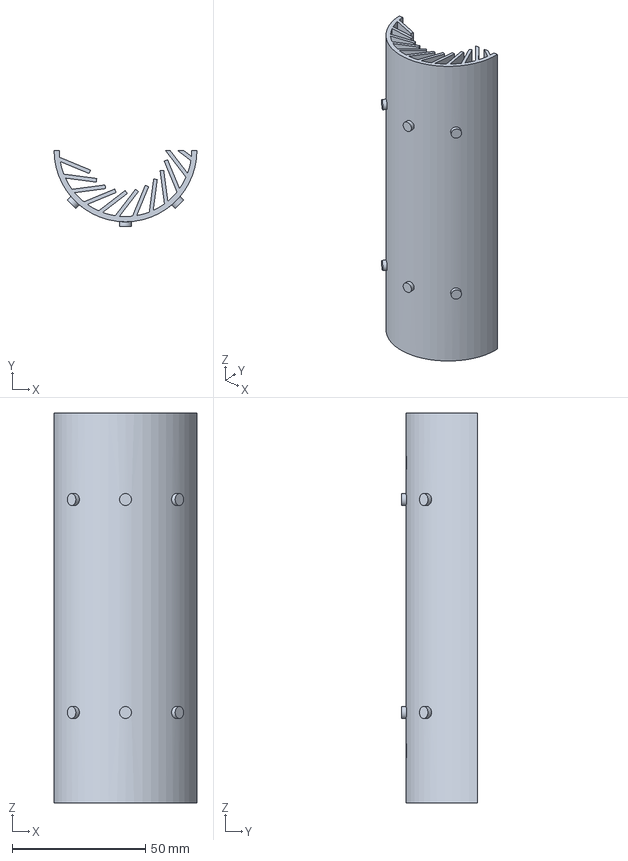
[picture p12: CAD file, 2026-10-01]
releases/rev3f/STEP/04_tpu_after_fit/16_liner_left_TPU95A_rev3f.step
53.7 x 28.6 x 146.5 mm

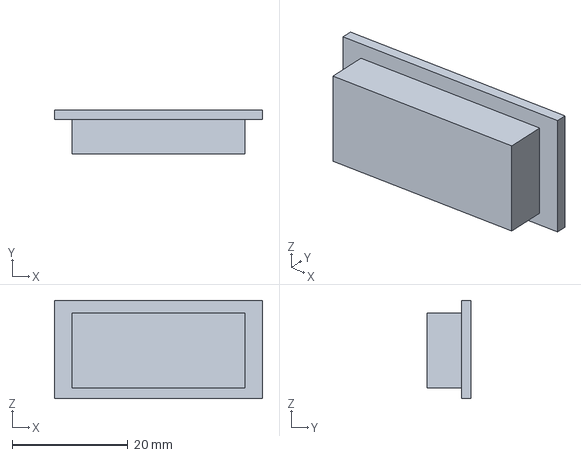
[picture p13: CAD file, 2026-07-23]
cad/step/mock_mt3608.step
36.0 x 7.60 x 17.0 mm

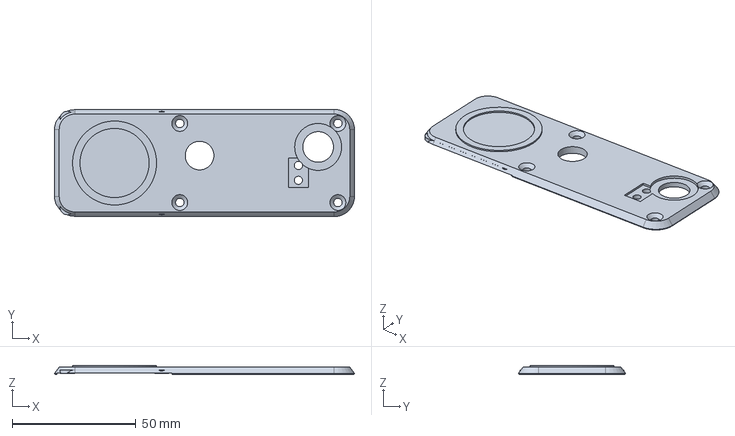
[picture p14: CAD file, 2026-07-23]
cad/step/placed/04_lid.step
121.4 x 43.4 x 3.60 mm

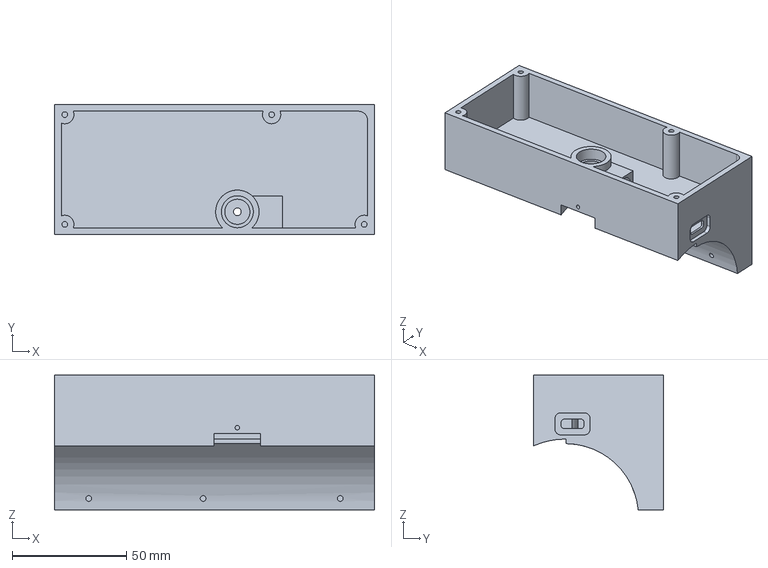
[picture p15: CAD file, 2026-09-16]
cnc-design/step/A1_top_box.step
140.0 x 57.0 x 59.0 mm

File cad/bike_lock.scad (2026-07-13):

// =====================================================================
// RFID Bike Lock — parametric housing, v0.2 (industrial-design pass)
// Matches DESIGN.md rev 0.1 (§6). Units: mm.
//
// v0.2 applies FDM design-for-manufacturing and product-design rules:
//   * one radius family: R14 belt / R11 pod corners / R3 details / 1.2 edge breaks
//   * drafted (tapering) pod walls, uniform ~3 mm wall thickness
//   * belt band wraps the body; the closure skirt IS the belt's left half,
//     so the part line is a design line (shadow gap), not an afterthought
//   * fairings blend pod->tube and drum->body (teardrop), overhangs <= 45°
//   * modeled wiring: floor raceways with clip lips, driver tray with wire
//     slot, battery cradles with zip-tie slots, strain-relief post
//
// VERIFY = measure your real part first.  TODO = refine after fit print.
// =====================================================================

// ---------------- what to render ----------------
part = "assembly"; // ["assembly", "shell_right", "shell_left", "lid", "liner_right", "liner_left", "shim", "spool_cover", "section_latch", "section_clamp", "section_wiring"]

$fn = 96;
eps = 0.01;

// ---------------- core (DESIGN.md §6.1) ----------------
shell_id   = 54;
shell_wall = 4;
shell_len  = 150;
R_in  = shell_id/2;
R_out = R_in + shell_wall;

// ---------------- top pod (§6.5) ----------------
pod_ix   = 150;
pod_iy   = 55;
pod_wall = 3;
pod_h    = 34;
lid_t    = 3;
z_crown  = R_out;
z_lid0   = z_crown + pod_h;
z_lidtop = z_lid0 + lid_t;
pod_ox   = pod_ix + 2*pod_wall;
pod_oy   = pod_iy + 2*pod_wall;
draft    = 1.8;    // pod side draft, base->lid (product taper + easy release)
r_pod    = 11;     // pod corner radius
r_belt   = 14;     // belt corner radius
edge     = 1.2;    // universal edge-break chamfer

// ---------------- belt band (closure skirt = its left half) ----------------
belt_t   = 4;                      // band stand-off each side
belt_z0  = 14;                     // bottom of band
belt_z1  = z_crown + 8;            // top of band (= lip hook height, 39)
belt_oy  = pod_oy + 2*belt_t;      // 69
gap      = 0.8;                    // shadow-gap groove width
clr      = 0.5;                    // closure engagement clearance  TODO tune

// ---------------- latch (§6.4) ----------------
bore_d      = 11;
bore_depth  = 26;
bore_x      = 58;
bore_y      = -pod_iy/2 + 14;
boss_d      = bore_d + 8;
pin_d       = 4.2;
head_seat   = 11.5;  // deep enough that solenoid body top (axis+7.5) clears the lid
pin_z       = z_lidtop - head_seat;
closure_screw_d = 4.4;
sol_x0      = 66;    sol_len = 30;   sol_w = 13.4;   sol_h = 15;
sol_axis_h  = 7.5;   // VERIFY
sol_hole_dx = 24;    // VERIFY
sol_hole_d  = 2.2;
ped_top     = pin_z - sol_axis_h;

// ---------------- lid features ----------------
pn532_x = 2;  pn532_l = 43.2;  pn532_w = 41.0;   // VERIFY board
window_remain = 1.2;
nfc_cx = 23.5;                       // embossed target ring center
button_d = 12.4;  button_x = 52;  button_y = 12; // VERIFY thread
led_d = 3.3;
usb_slot_w = 10;  usb_slot_h = 4;  usb_y = 15;  usb_z = z_crown + 12;
camlock_d = 16.4;                    // VERIFY

// ---------------- liner (§6.2) ----------------
fin_n = 24;  fin_h = 12;  fin_t = 1.4;  fin_lean = 30;  liner_base = 2;

// ---------------- spool pod (§6.3) ----------------
drum_od = 95;  drum_w = 34;  drum_wall = 3;  drum_x = 75;
drum_overlap = 5;                    // reduced: clamshell swing clearance
drum_cz = -(R_out + drum_od/2 - drum_overlap);
cable_exit_d = 8;

// ---------------- hinge ----------------
hinge_od = 8;  hinge_hole = 3.2;
hinge_cz = -R_out - hinge_od/2 + 2;
hinge_right = [[6,20],[34,48],[102,116],[130,144]];
hinge_left  = [[20,34],[48,58],[96,102],[116,130]];
hinge_gap = 0.4;

// ---------------- closure pad ----------------
lip_in = 4;  pad_l = 26;  pad_w = 16;  pad_h = 6;

// =====================================================================
// 2D / solid helpers
// =====================================================================
module rrect(l, w, r) { // rounded rect, corner at origin
    hull() for (x = [r, l-r]) for (y = [r, w-r]) translate([x, y]) circle(r);
}
// drafted rounded slab: base (l,w) at z0, shrinks by 2*d at z1
module rslab_draft(l, w, z0, z1, r, d) {
    hull() {
        translate([0, 0, z0]) linear_extrude(eps) rrect(l, w, r);
        translate([d, d, z1-eps]) linear_extrude(eps) rrect(l-2*d, w-2*d, max(r-d, 1));
    }
}
// straight rounded slab with a chamfered bottom edge (prints cleanly)
module rslab_cham(l, w, z0, z1, r, ch) {
    hull() {
        translate([ch, ch, z0]) linear_extrude(eps) rrect(l-2*ch, w-2*ch, max(r-ch,1));
        translate([0, 0, z0+ch]) linear_extrude(z1-z0-ch) rrect(l, w, r);
    }
}
module tube_bore()   { rotate([0,90,0]) translate([0,0,-6]) cylinder(r=R_in, h=shell_len+12); }
module outer_cyl()   { rotate([0,90,0]) translate([0,0,-1]) cylinder(r=R_out, h=shell_len+2); }
module half_space(right=true) {
    if (right) translate([-60, 0, -250]) cube([shell_len+120, 200, 500]);
    else       translate([-60, -200, -250]) cube([shell_len+120, 200, 500]);
}

module knuckles(spans) { for (s = spans) translate([s[0], 0, hinge_cz]) rotate([0,90,0]) cylinder(d=hinge_od, h=s[1]-s[0]); }
module knuckle_clearance(spans) { for (s = spans) translate([s[0]-hinge_gap, 0, hinge_cz]) rotate([0,90,0]) cylinder(d=hinge_od+2*hinge_gap, h=s[1]-s[0]+2*hinge_gap); }
module hinge_drill() { translate([-6, 0, hinge_cz]) rotate([0,90,0]) cylinder(d=hinge_hole, h=shell_len+12); }

// =====================================================================
// BODY FORMS (shared by both halves, cut at the Y=0 plane)
// =====================================================================
module pod_form(g=0) { // drafted capsule; g grows it for clearance cuts
    translate([-pod_wall-g, -pod_oy/2-g, 0]) rslab_draft(pod_ox+2*g, pod_oy+2*g, belt_z0-2*g, z_lid0+2*g, r_pod+g, draft);
}
module pod_interior() { // same draft -> uniform 3 mm walls
    difference() {
        translate([-pod_wall+pod_wall, -pod_iy/2, 0]) rslab_draft(pod_ix, pod_iy, belt_z0-2, z_lid0+1, r_pod-1, draft);
        outer_cyl(); // floor follows the shell surface
    }
}
module belt_form() { // full wrap band, chamfered bottom
    translate([-pod_wall-belt_t, -belt_oy/2, 0]) rslab_cham(pod_ox+2*belt_t, belt_oy, belt_z0, belt_z1, r_belt, edge*2);
}
module belt_groove() { // shadow gap where belt meets pod, all the way round
    translate([-pod_wall-belt_t-1, -belt_oy/2-1, belt_z1-gap])
        difference() {
            linear_extrude(gap+eps) rrect(pod_ox+2*belt_t+2, belt_oy+2, r_belt);
            translate([belt_t+1-gap, belt_t+1-gap, -1]) linear_extrude(gap+2) rrect(pod_ox+2*gap, pod_oy+2*gap, r_pod+gap);
        }
}
module side_fairing() { // pod -> tube blend, both sides, <=45° faces
    hull() {
        translate([-pod_wall, -pod_oy/2, 0]) translate([0,0,belt_z0]) linear_extrude(1) rrect(pod_ox, pod_oy, r_pod);
        translate([2, -22, 5]) linear_extrude(1) rrect(pod_ox-10, 44, r_pod);
    }
}
module drum_fairing() { // teardrop blend drum -> body
    hull() {
        translate([drum_x - drum_w/2, 0, drum_cz]) rotate([0,90,0]) cylinder(d=drum_od, h=drum_w);
        translate([drum_x - drum_w/2 - 8, -19, -R_out-4]) cube([drum_w+16, 38, 6]);
    }
}
module drum_hollow() {
    translate([drum_x - drum_w/2 + drum_wall, 0, drum_cz]) rotate([0,90,0]) cylinder(d=drum_od-2*drum_wall, h=drum_w);
}
module cover_rabbet() { // recessed seat so the cover sits flush
    translate([drum_x + drum_w/2 - 3, 0, drum_cz]) rotate([0,90,0]) cylinder(d=drum_od - 2, h=3.2);
}
module snout() { // cable-exit teardrop
    translate([drum_x, 0, drum_cz]) rotate([30,0,0]) translate([0,0,-drum_od/2+2]) hull() {
        sphere(d=cable_exit_d+7);
        translate([0,0,8]) sphere(d=cable_exit_d+11);
    }
}
module snout_drill() {
    translate([drum_x, 0, drum_cz]) rotate([30,0,0]) translate([0,0,-drum_od/2-9]) cylinder(d=cable_exit_d, h=22);
}
module usb_niche() { // sheltered recess around the port, in the rear belt face
    translate([pod_ix+pod_wall+belt_t-2.5, usb_y - usb_slot_w/2 - 3.5, usb_z - 3.5]) cube([6, usb_slot_w+7, usb_slot_h+7]);
}
module usb_drill() { translate([pod_ix - 2, usb_y - usb_slot_w/2, usb_z]) cube([2*pod_wall + belt_t + 4, usb_slot_w, usb_slot_h]); }
module camlock_drill() { translate([bore_x, -pod_oy/2 - 2, z_crown + pod_h*0.62]) rotate([-90,0,0]) cylinder(d=camlock_d, h=pod_wall + 4); }
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

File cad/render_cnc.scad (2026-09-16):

// CNC casing renders (cad/cnc_casing_cq.py parts). Variables:
//   view = iso | exploded | end | section | open | interior | latch (= section, camera on the latch column)
//   section reads cnc-design/stl/section/ (16 mm slab through the latch - cut in CadQuery because
//   OpenSCAD preview paints intersection() black); open reads cnc-design/stl/open/ (C2 set pre-rotated).
//   interior = A1 with the lid + insert removed, electronics reference bodies coloured.
view = "iso";
dir = view == "section" ? "section/" : (view == "latch" ? "latch/" : "");
module part(f, c, t = [0, 0, 0], d = dir) { color(c) translate(t) import(str("../cnc-design/stl/", d, f, ".stl")); }
module refs(e = 0) {
  part("ref_tray", "#B9A46B", [0, 0, e]);          part("ref_battery", "#3B6FB6", [0, 0, e]);
  part("ref_reader", "#2E8B57", [0, 0, e]);        part("ref_solenoid", "#E8842A", [0, 0, e]);
  part("ref_driver_card", "#B5651D", [0, 0, e]);   part("ref_plunger", "#C8CDD2", [0, 0, e]);
  part("ref_nano", "#2F6F8F", [0, 0, e]);          part("ref_tp4056", "#8B3A62", [0, 0, e]);
  part("ref_mt3608", "#4F7942", [0, 0, e]);        part("ref_buzzer", "#5E3A87", [0, 0, 2 * e]);
  part("ref_button_green", "#2E7D32", [0, 0, 2 * e]); part("ref_button_red", "#C62828", [0, 0, 2 * e]);
  part("ref_led_1", "#D33", [0, 0, 2 * e]);        part("ref_led_2", "#3C3", [0, 0, 2 * e]);
  part("ref_cap", "#B8860B", [0, 0, e]);            part("ref_ret_spring", "#9E9E9E", [0, 0, e]);
  part("ref_bushing", "#8A6D3B", [0, 0, 2 * e]);    part("ref_head", "#6D6D6D", [0, 0, 2.6 * e]);
  part("ref_ejector", "#9E9E9E", [0, 0, e]);        part("ref_closure_screw", "#404040", [0, 0, e]);
}
module c1side(e = 0, lid = true) {
  part("C1_chassis_half", "#7A8A99");
  part("A1_top_box", "#C0C6CC", [0, 0, e]);
  if (lid) { part("A2_lid", "#E8ECEF", [0, 0, 2 * e]); part("A5_window_insert", "#1E1E1E", [0, 0, 2.6 * e]); }
  part("A3_bottom_box", "#B0B8BF", [0, 0, -e]);
  part("A4_cover_plate", "#D8DDE2", [0, 0, -2 * e]);
  part("hinge_pin", "#404040", [1.6 * e, 0, 0]);
  part("liner_right", "#2E2E2E", [0, 0.5 * e, 0]);
  refs(e);
}
module c2side(dy = 0, d = dir) {
  part("C2_clamp_half", "#5A6A79", [0, dy, 0], d);
  part("closure_block", "#D95D39", [0, dy, 0], d);
  part("hinge_block", "#D95D39", [0, dy, 0], d);
  part("liner_left", "#2E2E2E", [0, dy, 0], d);
}
if (view == "iso" || view == "end" || view == "section" || view == "latch") { c1side(0); c2side(); }
if (view == "exploded") { c1side(22); c2side(-30); }
if (view == "open") { c1side(0); c2side(0, "open/"); color("#9BB7A0", 0.9) rotate([0, 90, 0]) translate([0, -60, -5]) cylinder(h = 160, d = 46, $fn = 96); }
if (view == "interior") { c1side(0, false); c2side(); }

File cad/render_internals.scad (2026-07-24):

// Internal-assembly documentation views (v0.8.3c) — composites the CadQuery STLs.
// Usage: openscad -D 'view="pod_deck"' (pod_deck | cart_module | pod_rfid | bay | bay_tray)
view = "pod_deck";

module electronics_colors() {}

module cart_module() {
    color("#D95D39") import("../stl/pedestal_cart.stl");        // ORANGE = pedestal cart
    color("#9AA0A8") import("../stl/mock_solenoid.stl");
    color("#22703A") import("../stl/mock_driver_stack.stl");
    color("#22703A") import("../stl/mock_mt3608.stl");
}

module pod_deck() {
    color("#5A748C") import("../stl/body.stl");
    cart_module();
    color("#C8A24B") import("../stl/mock_cable_head.stl");
    color("#22703A") import("../stl/mock_nano.stl");
    color("#D95D39") import("../stl/nano_clamp.stl");
    color("#8A2F2F") import("../stl/mock_led.stl");
}

module pod_rfid() {
    pod_deck();
    color("#22703A") import("../stl/mock_pn532.stl");
    color("#3B3B3B") import("../stl/mock_button.stl");
    %color("#C8CDD2") translate([0, 0, 14]) import("../stl/lid.stl");  // lid ghosted, lifted 14
}

module bay() {
    color("#22303C") import("../stl/bay_module.stl");
    color("#22703A") import("../stl/mock_tp4056.stl");
    color("#B8BDC4") import("../stl/mock_lipo.stl");
}

module bay_tray() {
    bay();
    color("#455A64") translate([4, 27.5, -73]) import("../stl/bay_hatch.stl");  // dropped 12 for view
}

if (view == "pod_deck") pod_deck();
if (view == "cart_module") cart_module();
if (view == "pod_rfid") pod_rfid();
if (view == "bay") bay();
if (view == "bay_tray") bay_tray();

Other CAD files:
newest-design/placed/05_pedestal_cart_v083.step
newest-design/usb_plug_v083.step
releases/rev3f/STEP/01_fit_coupons/02_horizontal_latch_coupon_PETG_rev3f.step
releases/rev3f/STEP/02_electronics_and_latch/07_ref_tray_PETG_rev3f.step
cad/render_latch_anim.scad
archive/v0.3/render_v03.scad
archive/v0.3/step/battery_saddle.step
archive/v0.3/step/board_pocket.step
archive/v0.3/step/driver_tray.step
archive/v0.3/step/drum_module.step
archive/v0.3/step/end_plug.step
archive/v0.3/step/lid.step
archive/v0.3/step/liner_left.step
archive/v0.3/step/liner_right.step
archive/v0.3/step/pedestal_cart.step
archive/v0.3/step/shell_left.step
archive/v0.3/step/shell_right.step
archive/v0.3/step/shim.step
archive/v0.3/step/spool_cover.step
archive/v0.4/render_v04.scad
archive/v0.4/step/bay_hatch.step
archive/v0.4/step/bay_module.step
archive/v0.4/step/bike_lock_assembly.step
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

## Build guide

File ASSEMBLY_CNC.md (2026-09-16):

# ASSEMBLY_CNC.md — building the rev 3e lock, step by step

The complete build order for the CNC-lineage casing (`cad/cnc_casing_cq.py`, rev 3e),
Stage 1: **everything printed in PETG + TPU**, aluminium later with no geometry change.

Read §0 once. After that the stages are meant to be followed in order — each one ends at a
test you can actually fail, so a mistake surfaces while it is still cheap to fix.

Coordinates match the CAD and the drawings: **x** runs along the tube 0→150, **y = 0** is the
seam plane (+y = C1, the half that carries the boxes), **z** is up, tube axis at z = 0.

---

## 0. Before you start

### 0.1 The parts you print

| Part | File | Print orientation | Material | Supports |
|---|---|---|---|---|
| C1 chassis half | `C1_chassis_half.step` | seam face **down** on the plate | PETG | none |
| C2 clamp half | `C2_clamp_half.step` | seam face **down** | PETG | none |
| A1 top box | `A1_top_box.step` | **open pocket up**, saddle down | PETG | yes, under the saddle |
| A2 lid | `A2_lid.step` | flat, **underside down** | PETG | none |
| A3 spool puck + cradle | `A3_bottom_box.step` | **puck opening up** (cradle down) | PETG | yes, under the cradle |
| A4 puck cover | `A4_cover_plate.step` | flat | PETG | none |
| A5 window insert | `A5_window_insert.step` | flange down | PETG (opaque) | none |
| Closure block | `closure_block.step` | flat top down | PETG | none |
| Hinge block | `hinge_block.step` | flat top down | PETG | none |
| Liner right / left | `liner_right.step`, `liner_left.step` | **on end (vertical)**, 5 mm brim | TPU 95A | none |
| Electronics tray | `ref_tray.stl` | **deck down** (the big flat face), walls up | PETG | none — it has no floor, so nothing bridges |
| Latch prototypes | `proto/proto_cable_head.stl`, `proto_cap.stl`, `proto_bushing.stl` | head **nose down** + brim · cap **flange down** · bushing on end | PETG, 0.12 mm layers | none |

STLs for all of these are in `cnc-design/stl/` (the STEP files are for the machine shop; the
slicer wants the STLs). **A1 prints with its Ø8.1 / Ø10.1 latch tunnel horizontal** — expect
slight ovality; run an 8 mm drill through the Ø8.1 section by hand before fitting the cap.
The Ø2.5 screw pilots self-tap M3 in PETG; drive each screw once into an empty hole first.

**Suggested print order** — test the mechanism before you print the tube:
1. A1, A2, A5, the tray, the three latch prototypes → dry-fit the electronics, then the
   latch (Stage D′ with the printed cap and bushing, Stage F′'s printed head on a cord).
2. Closure block, hinge block, A3, A4 → the hinge and the spool.
3. C1, C2 → the clamshell.
4. Liners last, in TPU, once the tube halves exist to test the stud fit.

**PETG:** 0.2 mm layers, 4 perimeters, 40 % gyroid, 240/80 °C, 40 mm/s on external walls.
**TPU 95A:** 0.2 mm, 3 perimeters, 20 % gyroid, 225/50 °C, **20–25 mm/s**, retraction ≤ 1 mm,
direct drive strongly preferred. Vertical orientation matters: the liner profile is a
constant section, so every layer is the same slice and the fins come out clean.

### 0.2 The parts you buy

**Hinge pin: ISO 2338 stainless dowel pin, Ø5 h8 × 36** (or ISO 8734 hardened 5 m6 × 36 —
either runs in the Ø5.1 bores; nothing to make) · Ø5 × 2 plug (a 2 mm slice of the same
Ø5 stock, set with Loctite 638 — the bore is 5.1, so it is a retained slip fit, not a press)
· M3 hardware below ·
3 mm 7×7 stainless cable coated to Ø4, 1.6 m · 2 swage sleeves · donor retractable reel ·
electronics per `BOM.md`.

**Latch train (rev 3e) — one lathe session, three parts from Ø14 and Ø10 O1 drill rod:**
the **cap** (Ø8 × 10, Ø10 × 2 flange, Ø6.1 × 8 bore), the **mouth bushing** (Ø10.3 ID × Ø14 OD
× 10.55) and the **cable head** (Ø10, Stage F′). O1 because it is cheap, turns easily soft, and
hardens with a torch and a can of oil; 4140 pre-hard is the no-torch fallback for all three.
Also: Ø2 × 8 roll pin · **ejector spring** Ø9 OD × 11 free, solid ≤ 4.5, ~0.5 N/mm · M3 × 6
low-head cap + Ø7 washer (closure). The **return spring is the solenoid's own front spring**,
cut to 10 mm free (Stage D′). **Print the prototypes first:** `cnc-design/stl/proto/` has all
three lathe parts as PETG prints so the latch action can be tested before any steel is cut.

### 0.3 Every screw in the lock

| Joint | Screw | Qty | Where it goes |
|---|---|---|---|
| Joint | Screw | Qty | Where it goes | Thread engagement (audited) |
|---|---|---|---|---|
| A1 → C1, crown row | **M3 × 10 countersunk 90°** | 3 | vertical, from inside the bore at y = +6, x 25 / 75 / 135 | 5.5 mm in a 6.0 pilot |
| A1 → C1, skirt row | **M3 × 10 countersunk 90°** | 3 | horizontal (+y), from inside the bore at z = +8, same x | 5.5 mm in 11 |
| A3 → C1, crown row | **M3 × 10 countersunk 90°** | 2 | vertical, from inside the bore at y = +10, x 40 / 100 | 5.5 mm in 6.8 |
| A3 → C1, skirt row | **M3 × 10 countersunk 90°** | 2 | horizontal (+y), at z = −8, x 40 / 100 | 5.5 mm in 12 |
| Closure block → C2 | **M3 × 10 countersunk 90°** | 2 | vertical, from inside the bore at y = −7, x 83.5 / 96.5 | 5.8 mm, tapped through the steel block, tip stays inside it |
| Hinge block → C2 | **M3 × 10 countersunk 90°** | 2 | vertical down, from inside the bore at y = −11.9, **x 64 / 92** | 5.8 mm in 7.8 |
| A2 lid → A1 | **M3 × 8 countersunk 90°** | 4 | (14.5, −9.5) (14.5, 38.5) (145.5, −9.5) **(105, 38.5)** | 4.8 mm in 8 |
| A4 cover → A3 | **M3 × 6 countersunk 90°** | 4 | (50, ±20) (90, ±20) — a Ø56.5 bolt circle in the puck wall | 4.8 mm in 8 |
| Closure screw (the consumer one) | **M3 × 6 countersunk 90° + M3 washer** | 1 | down the latch bore into the closure block | 4.0 mm in the steel block; **an 8 pokes through the block into C2's wall** |

So the whole lock is **14 × M3 × 10, 4 × M3 × 8, 5 × M3 × 6 — all ISO 10642 countersunk flat
head** (hex or Torx, stainless). Every row is what `python cad/cnc_casing_cq.py --audit`
reports for that joint: it walks each screw axis through the model, measures the free run to
the first thread and the tapped length available, checks the tip lands in air, and grades the
manual's length. **Why countersunk, not low-head cap:** the twelve inside-the-bore screws seat
in 90° countersinks in the tube wall, head top 0.4 mm below the bore surface, so the liner
ring passes over them. A cap head needs a 2.3 mm counterbore, and on this wall curvature that
leaves only 1.8 mm of aluminum at the counterbore's far edge; a countersink is deep only on
its axis and leaves > 3.4 mm everywhere (both are gated).

⚠️ **Countersunk** matters on the twelve inside-the-bore screws. Any head with a flat underside
(cap, button, pan) sits on the bore surface, stands 2–3 mm proud and the liner ring lands on it.

### 0.4 Tools

Hex drivers 2 mm and 2.5 mm · soldering iron with a fine tip · Ø2.5 mm drill (chasing print
pilots) · Ø4.2 mm drill (liner stud holes if they print tight) · small file · flush cutters ·
multimeter · wire strippers · crimpers for the swage sleeves (or a vise) · thread locker is
**not** used anywhere.

---

## 1. Stage A — clean the printed parts (30 min)

1. **Chase every tapped pilot with a Ø2.5 drill by hand.** The 22 pilots are modeled at Ø2.5
   so the M3 screws self-tap in PETG. Chasing them removes the first-layer squish and stops
   the plastic from splitting when the screw goes in.
2. **Test every screw in its own hole before anything is assembled.** Drive an M3 × 8 into
   each pilot, back it out, do the next. If one strips, drop a Ø2.5 nylon plug in and re-drill.
   Finding a stripped hole now costs nothing; finding it in stage E costs a teardown.
3. **Check the six liner stud holes per half** (Ø4.2 × 2 deep, at x 35 and 115, at −45° / 0°
   / +45° from each half's mid-arc). If your printer closed them up, open with a Ø4.2 drill
   held square to the wall — 2 mm deep only, the wall is 4.75.
4. **Deburr the bore.** Run a finger around the ten counterbores; scrape any lip flush so the
   liner sits flat.
5. **Fit-check the two halves dry**, no liner, no boxes: seam faces should meet with no rock.

---

## 2. Stage B — the hinge (20 min)

This is the joint everything else hangs off, so it comes first and gets tested alone.

1. **Hinge block onto C2.** Sit it on C2's outer surface with its lug pointing +y, spanning
   x 66.3–89.7. From **inside the bore**, drive 2 × M3 × 10 countersunk down through C2's
   bottom wall at y = −11.9, x 64 and x 92, into the block. Snug, not gorilla-tight — PETG.
2. **Dry-hang C2 on A3.** Hold A3 (the spool puck) beside C2 so the hinge block's lug drops
   between A3's two lugs (x 58–66 and 90–98). The three bores should line up on one axis.
   If the lug is too wide, file its faces, not the bore — you have 0.3 mm of end float.
3. **Drive the pin.** Push the Ø5 × 36 dowel in from the **x = 58 face** (the −x end). It
   passes lug 1, the hinge block's lug, and stops in lug 2's blind bore at x 96. The pin
   travels along the shallow Ø6 scallop in the cradle's front edge (x 33–58) on its way in —
   that groove is the entry path, not a defect.
   *If it binds, back it out and ream the two A3 lugs with a Ø5.1 drill; never force it.*
4. **Swing test.** C2 should fall open under its own weight to about 60° and stop when the
   hinge block lands on the puck's flat top. That stop is designed; it is not a collision.
5. **Leave the Ø5 × 2 plug out for now.** It goes in at the very end, once you never intend
   to separate the halves again.

---

## 3. Stage C — the electronics, on the bench (2–4 h, spread over the checkpoints)

Nothing goes in the box until it works on the bench. Build up one block at a time.

**Full electrical detail — net list, the RC522 3.3 V trap, driver-card layout, expected
voltages at every step — is in [`WIRING.md`](WIRING.md). Read it before soldering.**

### C.1 Checkpoint 1 — reader + logic (parts you already own)

Breadboard the Nano and the RC522. **RC522 power is 3.3 V, never 5 V.**

| RC522 | Nano | | Panel part | Nano |
|---|---|---|---|---|
| SDA (SS) | D10 | | Green button | D3 → GND |
| SCK | D13 | | Red button | D2 → GND |
| MOSI | D11 | | Red LED + 470 Ω | D8 |
| MISO | D12 | | Green LED + 470 Ω | D9 |
| RST | D4 | | Active buzzer (+) | D6 |
| 3.3V | 3V3 | | Buzzer (−) | GND |
| GND | GND | | | |

Flash `firmware/rfid_bike_lock_rc522/`. Install the **MFRC522** library first (Library
Manager, by GithubCommunity). Serial monitor at 115200.

**Pass when:** green button → chirp + `[wake]` · first fob tapped becomes master · a second
fob gives two red blinks and a long buzz · hold red 5 s → three beeps, tap master, tap the
second fob → it enrolls and now unlocks · tap red briefly → one blink and back to sleep.

**If the reader is not found (fast red ×5):** check SS/RST pins first, then that the module's
header is actually soldered, then that you are on 3.3 V.

### C.2 Checkpoint 2 — the solenoid driver

Build this on a **42 × 10.7 mm card** cut from your perfboard. This card is what later rides
the solenoid cart, so keep it to size.

On the card: IRLZ44N laid flat, 1N5819, 1000 µF Ø8 × 12.5 cap lying down, 100 Ω gate
resistor, 100 kΩ gate pulldown.

```
battery + ──┬─────────────── solenoid coil ── IRLZ44N drain
            │                     │
         1000 µF              1N5819  (cathode to +, band to +)
            │                     │
battery − ──┴──── IRLZ44N source ─┴── GND (common with the Nano)
Nano D5 ── 100 Ω ── IRLZ44N gate ── 100 kΩ ── GND
```

Two rules that are easy to get wrong and expensive:

- **The diode band faces the + rail.** Backwards, it is a dead short across your battery.
- **The solenoid runs straight off the cell**, not off the boost. It is the one high-current
  load; the MT3608 only feeds the Nano and reader.

**Pass when:** an authorized tap gives a solid clunk, and the Nano does not reset when it
fires. A reset means the supply is sagging — check the reservoir cap is really across the
coil supply and not somewhere useless.

### C.3 Checkpoint 3 — power chain

1. Set the **MT3608 output before connecting anything to it.** Feed it from the cell, put a
   meter on the output, turn the pot until it reads **6.2-6.5 V**, then power down.
2. Nano runs off **VIN** from that 6 V rail. The RC522 and LEDs run off the **Nano's 3.3 V
   and 5 V pins** through the AO3401 gate on D7.
3. TP4056: cell to B+/B−, load to OUT+/OUT−. **Charge with the lock asleep** — this board has
   no load sharing and a scan during charging confuses its termination.
4. Battery sense: 100 kΩ from the cell + to A0, 100 kΩ from A0 to GND.

**Pass when:** sleep current measures **1.5–3 mA**. If you see 20 mA the Nano never slept —
the usual cause is a button held low or `#define DEBUG` still keeping serial alive.

---

## 4. Stage D — load the top box (1 h)

Work with A1 on the bench, lid off, **before it goes on the chassis.**

Positions below are the audited ones (`--audit` checks every module *plus the room its wires,
nuts, legs and plugs need*). Solder the wires onto each board **before** it goes in — the
wire zones are 3.5 mm tall and there is nothing taller available above any board edge.

1. **Print the tray** (`ref_tray.stl`, deck down). It is a table: two 1 mm walls either side
   of the cell carrying the 2 mm reader deck at z 53.5, with the reader-wire slot already in
   the deck at x 16.5–21.5. No floor — the cell sits on A1's own floor. The pigtail leaves
   at +x, where there is no wall.
2. **Battery** flat on A1's floor at x 19.5–69.5, y −7–27. Pigtail exits toward +x, then runs
   along the floor at y 6–11.5 (the strip between the latch boss and the Nano) to the TP4056.
3. **Reader** on the deck, board x 19–79, **antenna end toward +x** so it sits under the
   window, header end at x 19. **Solder its 7 wires on the UNDERSIDE** of the header pads and
   drop them through the deck slot — there is only 2 mm of foam above the board, not enough
   for solder joints on top. Component side up.
4. **Solenoid** on its two pillars at **x 110.8–139.4**, y −12.75–4.75 (pillars in the −y strip
   beside the TP4056, y −10.5 to −6). The coil face at x 110.8 is set by the plunger train
   (Stage D′), not by anything else — do not move it. Its coil leads leave the +x end.
5. **Driver card** standing beside the coil at x 102.5–142.5, y 5–15.7, base at z 45.15. Its
   wires leave both x ends (3 mm each) — the −x end sits just clear of the red button's body.
6. **Nano lying flat** at x 100.5–145.5, y 16–34, on the floor. **USB-C toward −x** (the open
   bay): with the lid off you can plug in a cable to reflash without removing anything. Trim
   the pins flush; solder wires onto the stubs along both long edges from the top.
7. **TP4056** on the floor at x 117–146, y −5.5–11.8; its USB-C receptacle projects 0.5 mm
   into the 10 × 4.2 wall slot so a plug shell actually reaches it (6 mm insertion). B±/OUT±
   pads are at its −x end, under the coil, with 6.6 mm of headroom.
8. **MT3608** on **11.5 mm standoffs** (board base at z 49.5) above the Nano, x 110–146,
   y 17–34 — 4 mm above the Nano's wire zone. Pads at both x ends, wires on top.
9. **Buzzer** seated 3 mm up into the lid recess at **(103.5, 22.85)** — over the Nano, where
   its 5 mm pins have 10 mm of air. **Not over the boost** (that is where it used to be; the
   pins would land on the inductor).
10. **Buttons** into the lid at x 93: green at (93, 32.5), red at (93, 13). Their Ø15 nuts
    clear the window flange, the latch boss and the lid-screw boss by design — if you use a
    button with a bigger nut, re-run the audit with `BTN_NUT_D` changed.
11. **LEDs** at **(23, 37.2) and (29, 37.2)** — the free strip along the +y wall at the −x end,
    beside the reader deck. Their legs and resistors hang into empty space there; two Ø15 nuts
    and two LEDs cannot share the 34 mm bay between the reader and the latch boss (the model
    proves it). Pot the domes with clear RTV.
9. **Window insert** from *underneath* the lid — its flange sits in the lid's underside
   recess. RTV bead around the flange.
10. Leave the lid loose. **Repeat checkpoint 1 with everything in the box** before you screw
    it down: the metal-free PETG box should not change anything, but this is the last easy
    look inside.
11. Lid on, 4 × M3 × 8 countersunk, with the EPDM foam strip on the rim.

---

## 4′. Stage D′ — the latch train (45 min, before the solenoid goes in)

The solenoid's soft plunger is never the latch pin. A hardened **cap** is.

1. **Cut the plunger's tail.** Push the plunger fully into the coil (seated). Mark the rod
   where it leaves the back frame and cut it there, removing the tail bolt/nut. The tail
   now ends flush at full retraction and sits 2.6 mm inside at rest.
2. **Free the front spring.** Your unit's return spring is on the front, held by a clip or
   collar near the nose. Remove that clip (the cap's flange takes over as the spring seat)
   and slide the spring off. **Cut it to 10 mm free length** — it has 7.3 mm of room at
   rest and 4.7 mm retracted, so a full-length spring goes solid and blocks the stroke. If
   it is thicker than ~0.7 mm wire it will be too stiff at that length; use a Ø9 × 10,
   ~0.4 N/mm spring instead. Keep it either way — it goes back on in step 4.
3. **Make the cap** (or print `proto_cap.stl` for the first test) from Ø10 O1: turn Ø8 × 8
   with the Ø10 × 2 flange at the rear (10 long), drill Ø6.1 × 8 from the flange end (2 mm
   end wall), cross-drill Ø2 through the wall 4 mm from the flange, 0.5 × 45° chamfer on the
   nose. Harden: heat to cherry red (~800 °C), quench in oil, temper 1 h at 200 °C (an oven
   does it). Then **press the cap over the plunger nose** until the nose bottoms, drill Ø2
   through the plunger using the cap's hole as the guide, drive the roll pin. For the
   printed prototype, a drop of CA glue instead of the pin is fine.
4. **Return spring** (the cut factory spring) over the plunger, against the flange.
5. **Fit the train into A1** from the cavity side: cap nose first into the Ø10.1 counterbore,
   through the step into the Ø8.1 tunnel until the flange meets the step. The nose should
   stand **2.0 mm into the receiver bore**. Then set the coil on its pillars so its face is
   1 mm behind the rib end (x 110.8) with the spring lightly compressed between flange and
   face. Bolt the coil down; wire it.
6. **Check the stroke** by pushing the plunger's tail forward with a pencil through the
   coil: the cap must retract until its nose is clear of the bore (you see the bore wall)
   and the plunger seats — that is 2.6 mm. Release: the spring returns it to the step.
7. **Mouth bushing** (or `proto_bushing.stl` for now): turn Ø14.02 OD × Ø10.3 ID × 10.55
   from O1, harden as the cap. Fit: either a **light press** (bushing 0.02–0.03 over the
   Ø14.00 seat — chill the boss or warm the bushing and tap it in with a Ø10 drift from
   above, lid off) or turn it Ø13.98 and set it with **Loctite 638** retaining compound,
   which is easier to get right and comes out with heat if it ever has to. Its top must
   end flush with the lid's top face once the lid is on; it passes through the lid's
   Ø14.1 hole with clearance.

**Pass when:** with the coil driven (bench sketch), the cap visibly retracts and returns
with a click, and a Ø10 rod dropped down the bushing is stopped by the cap's nose.

---

## 5. Stage E — boxes onto the chassis (30 min)

Both boxes bolt to C1 **from inside the bore**, which is why the liner is not in yet.

1. **A1 first.** Sit it on C1's top so the saddle mates. Reach into the bore and start all
   six **M3 × 10 countersunk**: three vertical at y = +6 (x 25/75/135), three horizontal at
   z = +8 (same x).
   Start every screw before tightening any, then work them down in a crisscross.
2. **A3 second**, on the bottom: two vertical at y = +10 and two horizontal at z = −8, both
   at x 40 and 100 — all four **M3 × 10 countersunk**.
3. **Closure block onto C2** if you have not already: 2 × M3 × 10 countersunk from inside the bore at
   y = −7, x 83.5 and 96.5. Its flat top must end up at z = 36.5.
4. **Close the clamshell and test the latch alignment.** Swing C2 shut and look down the
   latch bore from the top: you should see the closure block's tapped hole centred in it. If
   it is off, the block is rotated on C2 — loosen, nudge, retighten.

---

## 6. Stage F — the spool (1 h, the fiddly one)

This is the only step the model does not fully define, because it depends on your donor reel.

1. **Gut the donor reel.** Keep the flat power spring, its hub, and the spool if it fits a
   Ø51 pocket. Wear eye protection — those springs are under tension and will escape.
2. **Wind the cable.** 1.5 m of Ø4 coated cable on a Ø32 core is 6 wraps a layer, two layers.
   Wind it on before the spool goes in the pocket.
3. **Swage a ball stop on the inner end.** This is a security feature, not a convenience: it
   is larger than the Ø7 exit, so even with the cover off and the spool out, the locked cable
   cannot be pulled free.
4. **Route the working end out the Ø7 exit** at the −x end of the puck. Fit a steel bushing
   in that hole if you have one; the cable saws plastic over time.
5. **Anchor the spring's outer end** to the pocket wall. Improvise: a slot filed in the wall,
   or a screw through the spring's eye. Preload it two or three turns before the cover traps it.
6. **Cover on**, 4 × M3 × 6 countersunk, gasket under it.
7. **Swage the cable head** on the working end. The head is a **Ø10 h9 hardened cylinder,
   ~22 long**: 3 mm 45° cone to a Ø4 tip, 3 mm land, an **8.5 wide × Ø6.8 groove — lower
   flank SQUARE (it carries the load), upper flank 45°** — then 5.5 mm of Ø10 and the Ø8
   ferrule bored Ø4.2 × 12 for the cable, swaged in. **First print `proto_cable_head.stl`**
   (PETG, nose down, brim): it has the same profile plus a Ø10 × 14 grip with a Ø3
   cross-hole, so a cord stands in for the cable and you can test insert / click / unlock /
   eject on the bench before the lathe. For the steel part: Ø10 O1, harden as the cap, and
   only the groove *width* and the *square lower flank* need to be right.

**Pass when:** pulling the cable out and letting go reels it fully in, and the head snaps
past the plunger and stays.

---

## 7. Stage G — liners (15 min)

1. **Dry-fit one half first.** The liner half should drop into the bore with its six studs
   near their holes.
2. **Press the studs in progressively**, starting at one end and working along. They are
   Ø4.5 TPU into Ø4.2 holes — a firm push each, not one big shove.
3. A smear of silicone grease on the bore makes this much easier and does no harm.
4. Repeat for the other half. Fins should lean the same way on both.

---

## 8. Stage H — on the bike (5 min, the consumer step)

1. Open C2 to its 60° stop.
2. Set C1 on the down tube. The fins compress; that is the whole fit mechanism.
3. Swing C2 shut. It should close with hand pressure alone.
4. **One M3 × 6 low-head cap on a Ø7 washer down the latch bore** into the closure block (long
   2.5 mm hex key through the bushing). Snug it; the liner preload is what holds the clamp,
   the screw just stops it opening. **Not a countersunk screw** — the bore floor is flat.
5. Drop the **ejector spring** (Ø9 × 11) into the bore; it sits on the floor around the screw
   head. Push the cable head in until it clicks; let go — it must stay. Fire an unlock: the
   head must pop up at least 5 mm and stay up.
6. **Set the Ø5 × 2 plug** in the pin bore's entry at x 58: a drop of Loctite 638 on it,
   push it flush against the pin's end, wipe. The bore is Ø5.1 so the plug is a slip fit;
   the retaining compound is what holds it (it fills 0.05 mm gaps and needs ~250 °C to
   release). From here the pin cannot be driven out — that is the point.
7. First boot: tap your chosen fob. It becomes master. Enroll the rest with the red button.

---

## 9. If something is wrong

| Symptom | Most likely cause |
|---|---|
| C2 will not close the last few mm | liner fins fouling the seam, or the closure block sitting proud of z 36.5 |
| C2 opens past 60° and jams | hinge block screws loose, so it is riding on the pin only |
| Screw spins forever in PETG | stripped pilot — plug with a Ø2.5 nylon rod and re-drill |
| Solenoid clunks weakly | it is on the boost rail instead of the cell, or the coil is a 12 V variant |
| Nano resets when the solenoid fires | reservoir cap not across the coil supply, or grounds not common |
| Reader works on the bench, not in the box | metal near the antenna, or the foam pad is too thick — the gap to the lid should be ~2 mm |
| Cable will not retract fully | spring preload lost during cover fitting; redo step 6.5 with one more turn |

---

## 10. What this manual does not cover

- **The donor spool anchoring** (§6.5) is the one improvised joint in the build. Everything
  else is dimensioned in the CAD.
- **Torque values.** PETG has no meaningful spec; snug plus a few degrees is the honest
  instruction. The aluminium version will get real numbers.
- **The firmware has never run on hardware.** Checkpoints 1–3 are the first time it will.

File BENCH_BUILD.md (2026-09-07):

# BENCH_BUILD.md — building from the MT3608 forward, with the parts on hand

Everything downstream of the charger, using only what has been delivered. The TP4056 hasn't
arrived, so the cell can't be recharged yet — this guide works around that by running the bench
off the ELEGOO supply and the RoomCleaner 12 V rig, and saving the LiPo for the tests that
actually need it.

**Bench wiring diagram: `renders/electrical/bench_wiring_esp32.png`** — exactly what to connect
now, on this board.

Full-system reference: [`WIRING.md`](WIRING.md) · diagram: `renders/electrical/wiring_diagram.png`
Firmware: `firmware/rfid_bike_lock_rc522/`

---

## 0. What you have, what's missing, and the workaround

| Needed | Status | Workaround until it arrives |
|---|---|---|
| MT3608 boost | ✅ delivered | — |
| HS-0730B solenoid, 6 V 1 A | ✅ delivered | — |
| IRLZ44N, 1N5819 | ✅ delivered | — |
| IRF4905 (P-FET reader gate) | ✅ delivered | use instead of the AO3401 — same circuit, TO-220 package |
| 103450 LiPo | ✅ delivered | ships part-charged (~3.7–3.8 V). **You cannot recharge it yet**, so use it only for stages 5–6 |
| **Arduino Nano ESP32**, RC522, buttons, LEDs, buzzer, resistors | ✅ owned | 3.3 V board — see the note below |
| **TP4056** | ❌ not ordered | none — the cell simply can't be recharged. Don't run it below 3.0 V |
| **AMS1117-3.3** | ❌ not ordered | the ELEGOO supply module's **3.3 V rail** powers the RC522 on the bench |
| **1000 µF cap** | ❌ not ordered | drive the coil from a *separate* supply in stage 5 so rail dips can't reset the Nano |

### The board is a Nano ESP32, which changes two stages

It is a **3.3 V** board, so the RC522 connects **directly — no level shifters, no AMS1117**.
That deletes eight resistors and one missing part from this build. Its VIN range is 6–21 V, so
the 6.2–6.5 V rail is valid (near the bottom, which is fine). Flash
`firmware/rfid_bike_lock_esp32/` — the AVR sketches will not compile on it. Board support:
Boards Manager → "Arduino ESP32 Boards" → *Arduino Nano ESP32*.

The board's **5 V pin is disabled behind a solder jumper and fed from USB only**. Leave it
alone; nothing in this design needs 5 V any more.

**Two rules for the whole session.** Set the MT3608's output *before* connecting anything to
it — they ship at 20 V and will kill the Nano. And the 1N5819's painted band goes to the
**positive** rail; backwards it is a dead short.

---

## Stage 1 — set the MT3608 to 6.2–6.5 V (10 min)

Nothing else connected. Feed it 5 V from the ELEGOO module (or 12 V from the RoomCleaner PSU
through an MP1584 — the MT3608 takes 2–24 V in).

1. IN+ / IN− to the supply. Multimeter on OUT+ / OUT−.
2. Turn the trim pot. Many turns do nothing at first; keep going, then it climbs fast.
3. Land on **6.2–6.5 V** (not 6.0: the Nano's regulator needs ~1.1 V of dropout). Power down.

Mark the module with tape so you don't confuse it with the other four in the pack, and put a
dot of nail polish or hot glue on the pot so vibration can't drift it.

> **Why not exactly 6.0?** The Nano's onboard AMS1117-5.0 drops about 1.1 V, so a 6.0 V rail
> leaves its 5 V output sagging near 4.9. 6.2–6.5 gives a solid 5 V for the reader and LEDs,
> and only pushes the 6 V solenoid ~7% over rating — irrelevant for a 300 ms pulse.

---

## Stage 2 — Nano on the 6 V rail (10 min)

| From | To |
|---|---|
| MT3608 OUT+ | Nano **VIN** |
| MT3608 OUT− | Nano **GND** |

| Measure | Expect |
|---|---|
| Nano **3V3** pin → GND | 3.25–3.35 V (its onboard regulator working) |
| VIN → GND | 6.2–6.5 V |

If the 3V3 pin reads 6 V you're on the wrong pin, and that would destroy the reader.

---

## Stage 3 — panel I/O, no reader yet (30 min)

This proves the sketch, the buttons, the LEDs and the buzzer before any reader complexity.

| Part | Nano pin | Wiring |
|---|---|---|
| GREEN button | D3 | one leg → D3, other leg → GND |
| RED button | D2 | same |
| Red LED | D8 | anode → **220 Ω** → D8, cathode → GND |
| Green LED | D9 | same on D9 |

⚠️ **220 Ω, not 470.** The 470 Ω figure was sized for a 5 V board; on 3.3 V it passes about
2.5 mA and the LEDs look dim.
| Active buzzer | D6 | (+) → D6, (−) → GND |

Flash `firmware/rfid_bike_lock_rc522/`. Install the **MFRC522** library first (Library Manager,
by GithubCommunity). Serial monitor at 115200.

**Expect:** press green → short chirp, `[wake]` on serial, then a fast red ×5 and a long buzz
because no reader answers. That failure *is* the pass condition for this stage — it means
buttons, LEDs, buzzer and the state machine all work.

Tap red during the window → one red blink, a 150 ms beep, back to sleep.

---

## Stage 4 — RC522 (15 min)   ✅ **PASSED 2026-09-07** — master fob enrolled

*If the reader misbehaves, flash `firmware/rc522_test/` first: 40 lines that print VersionReg
and any card UID, so you find the fault in one upload instead of guessing inside 440 lines of
lock firmware.*

Both parts are 3.3 V, so this is now seven wires and nothing else. **No dividers, no AMS1117,
no ELEGOO rail.**

| RC522 | Nano ESP32 |
|---|---|
| SDA (SS) | D10 |
| SCK | D13 |
| MOSI | D11 |
| MISO | D12 |
| RST | D4 |
| 3.3V | **3V3 pin** |
| GND | GND |

**Expect:** green button → chirp → tap a fob → `[scan] uid=…`. The first fob ever tapped
becomes master and is written to EEPROM. A second fob gives two red blinks and a long buzz.
Hold red 5 s → three beeps → tap master → tap the second fob → it enrolls, green ×3.

If you get the fast red ×5: check SS and RST first, then that 3.3 V is actually present at the
module, then that the dividers aren't swapped.

---

## Stage 5 — solenoid driver (45 min)

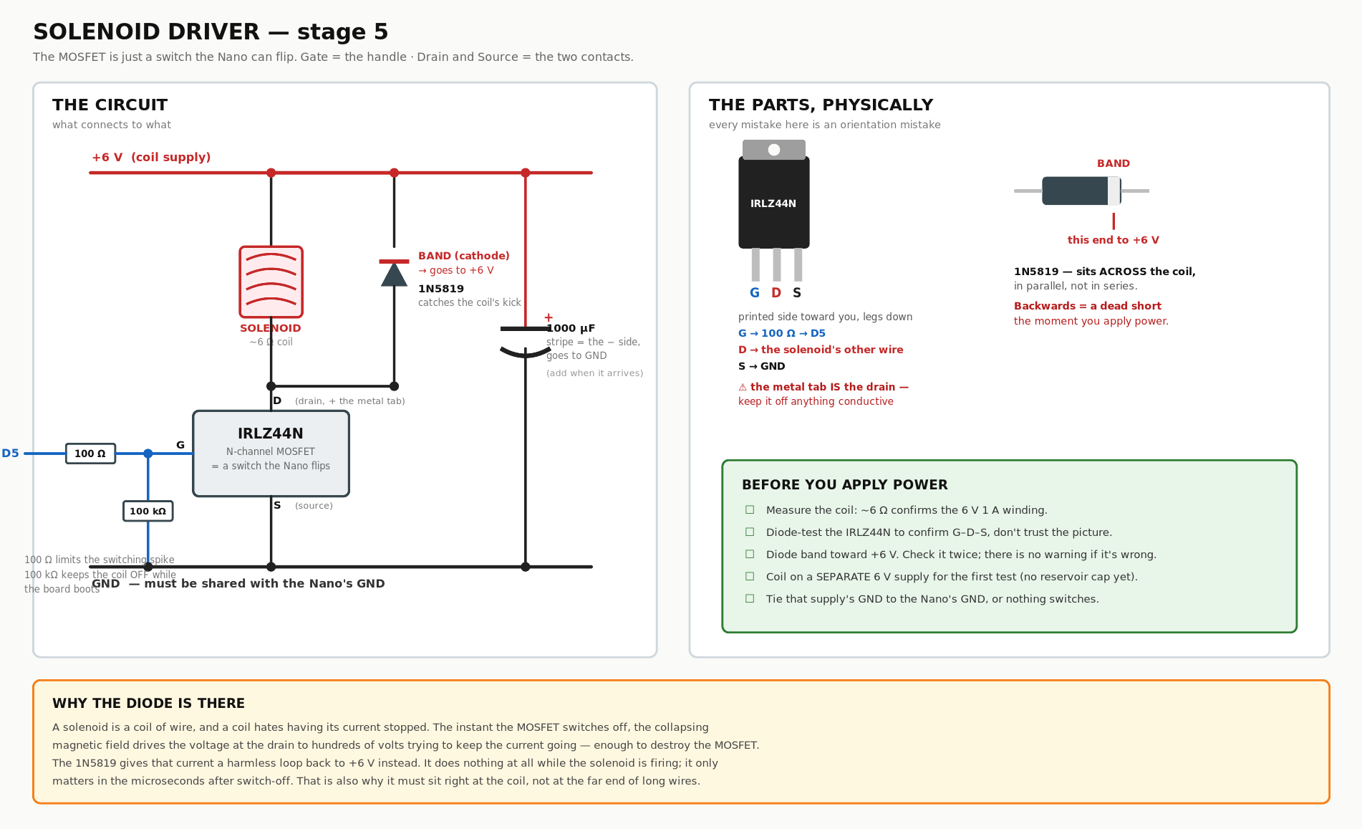
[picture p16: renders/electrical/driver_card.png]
driver card


*Circuit and physical parts side by side: `renders/electrical/driver_card.png`*

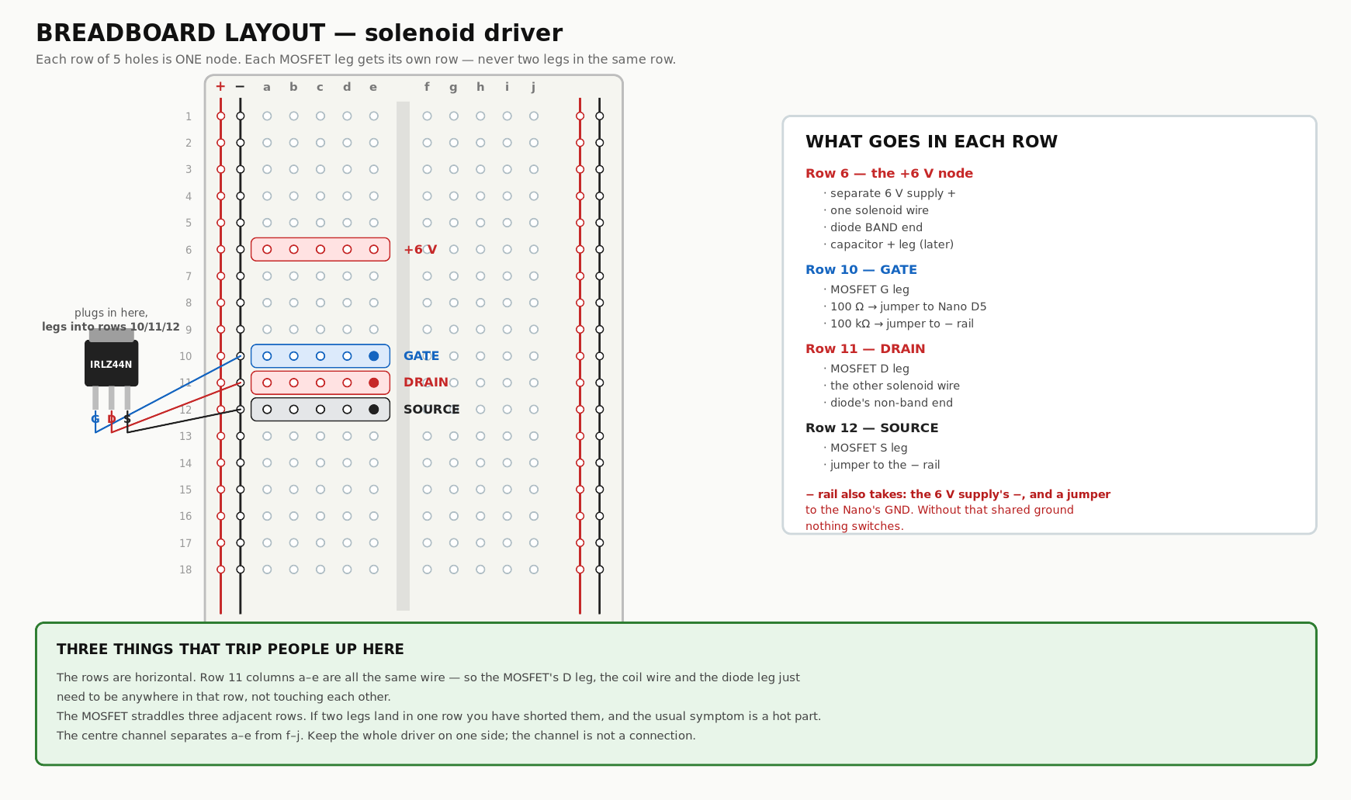
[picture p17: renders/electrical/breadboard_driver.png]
breadboard layout


*Row-by-row breadboard layout: `renders/electrical/breadboard_driver.png`*

Build the driver on a scrap of perfboard for now; cut the final 42 × 10.7 card later.

```
coil supply + ──┬──────────── solenoid ──── IRLZ44N drain
                │                 │
            (cap later)        1N5819   band toward +
                │                 │
coil supply − ──┴── IRLZ44N source ┴── GND, common with the Nano
Nano D5 ── 100 Ω ── IRLZ44N gate ── 100 kΩ ── GND
```

**Power the coil from a separate 6 V source for this first test** — the RoomCleaner 12 V PSU
through an MP1584 set to 6 V is ideal. Without the reservoir cap, a 1 A pulse on a shared rail
can dip it enough to reset the Nano, and you'd waste an hour chasing a fault that isn't there.
Grounds still tie together.

| Measure | Expect |
|---|---|
| Coil resistance before wiring | ~6 Ω (confirms the 6 V 1 A winding) |
| Across the coil, idle | 0 V |
| Across the coil during the 300 ms pulse | 5.5–6 V |
| Gate at D5 during the pulse | ~5 V |

**Easier than using the lock firmware for this:** flash `firmware/hw_selftest/`, a serial menu
that fires the solenoid on demand and tests every other subsystem separately. Run `a` first
(everything passive), then `3` for buttons, then `5` to fire.

**Expect:** an authorized fob → clunk. File the plunger's 45° nose before testing the latch
itself; for now you're only proving the electrical path.

If the pull feels weak, try `SOLENOID_PULSE_MS = 150` — shorter is fine, the plunger moves in
tens of milliseconds — and check you're at 6 V, not 5.

---

## Stage 6 — reader power gate (20 min) — OPTIONAL on this board

⚠️ **Skip this stage for now.** `READER_POWER_GATED` is 0 in the ESP32 sketch, so the reader
stays powered. The IRF4905 is a poor fit here: its gate threshold is −2 to −4 V and 3.3 V logic
can only reach −3.3 V, so it may never turn fully on or off. Do stage 7 first — if the sleep
current is acceptable without gating, you may not need this at all. When you do want it, use
the logic-level **AO3401** from the SOT-23 kit and set `READER_POWER_GATED` to 1.

<details><summary>Original IRF4905 wiring, for reference</summary>

The IRF4905 is a P-channel in TO-220. Facing the printed side with the legs down: **G – D – S**.
The metal tab is connected to the drain, so it sits at the load's voltage — keep it off
anything conductive.

| IRF4905 | To |
|---|---|
| **S** (source) | Nano 5V pin |
| **D** (drain) | reader supply (the AMS1117's input when it arrives; the RC522 directly for now, **only if you keep it on 3.3 V** — see note) |
| **G** (gate) | Nano D7, plus a 10 kΩ from gate to 5 V |

⚠️ **Do not feed the RC522 from the 5 V drain.** Until the AMS1117 arrives, leave the reader on
the ELEGOO 3.3 V rail and test the gate with an LED and resistor on the drain instead: D7 low →
LED on, D7 high → LED off. That proves the gate logic without risking the module.

| Measure | Expect |
|---|---|
| Drain to GND, D7 driven LOW | ≈ 5 V (FET on) |
| Drain to GND, D7 HIGH | ≈ 0 V (FET off) |

If it's backwards — on when it should be off — source and drain are swapped.
</details>

---

## Stage 7 — the sleep-current test (15 min, needs the LiPo)

This is the one that decides whether the lock lasts weeks or days. Now switch the MT3608's
input to the **LiPo**, since a bench supply's own draw would swamp the reading.

Meter in series with the cell's positive lead, sketch running, let the scan window expire.

⚠️ **The Nano ESP32 is not a low-power board.** Its USB bridge, RGB LED and regulator all draw
current in deep sleep, and published figures are milliamps rather than the microamps a bare
ESP32-S3 reaches. This measurement is therefore a genuine unknown, not a pass/fail against a
number I can promise you.

| Reading | Meaning |
|---|---|
| under 1 mA | excellent — months per charge |
| 1–5 mA | workable — days to weeks; matches the original design budget |
| 10 mA + | the board's own overhead dominates. Not a firmware bug. The fix is a bare ESP32-S3 module or a 3.3 V Pro Mini, both drop-in for this circuit |

Comment out `#define DEBUG` for this test; USB serial keeps the bridge awake.

**Watch the cell voltage.** You can't recharge until the TP4056 arrives, so stop at 3.4 V and
leave the rest for later.

---

## When the missing parts arrive

1. **TP4056** — cell to B+/B−, then OUT+/OUT− becomes the input to the MT3608. The cell is
   never tapped by anything else. Charge with the lock asleep; this board has no load sharing.
2. **AMS1117-3.3** — not needed any more on a 3.3 V board. If you later gate the reader's
   supply, use the **AO3401** from the SOT-23 kit: the IRF4905's −2 to −4 V threshold is
   marginal when 3.3 V logic can only pull its gate to −3.3 V.
3. **1000 µF (Ø8 × 12.5, or Ø10 up to 20 mm — both fit the driver card)** — across the coil
   supply, right at the card. Then move the coil onto the shared 6 V rail and re-run stage 5.

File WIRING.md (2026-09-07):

# WIRING.md — the electrical build, in detail

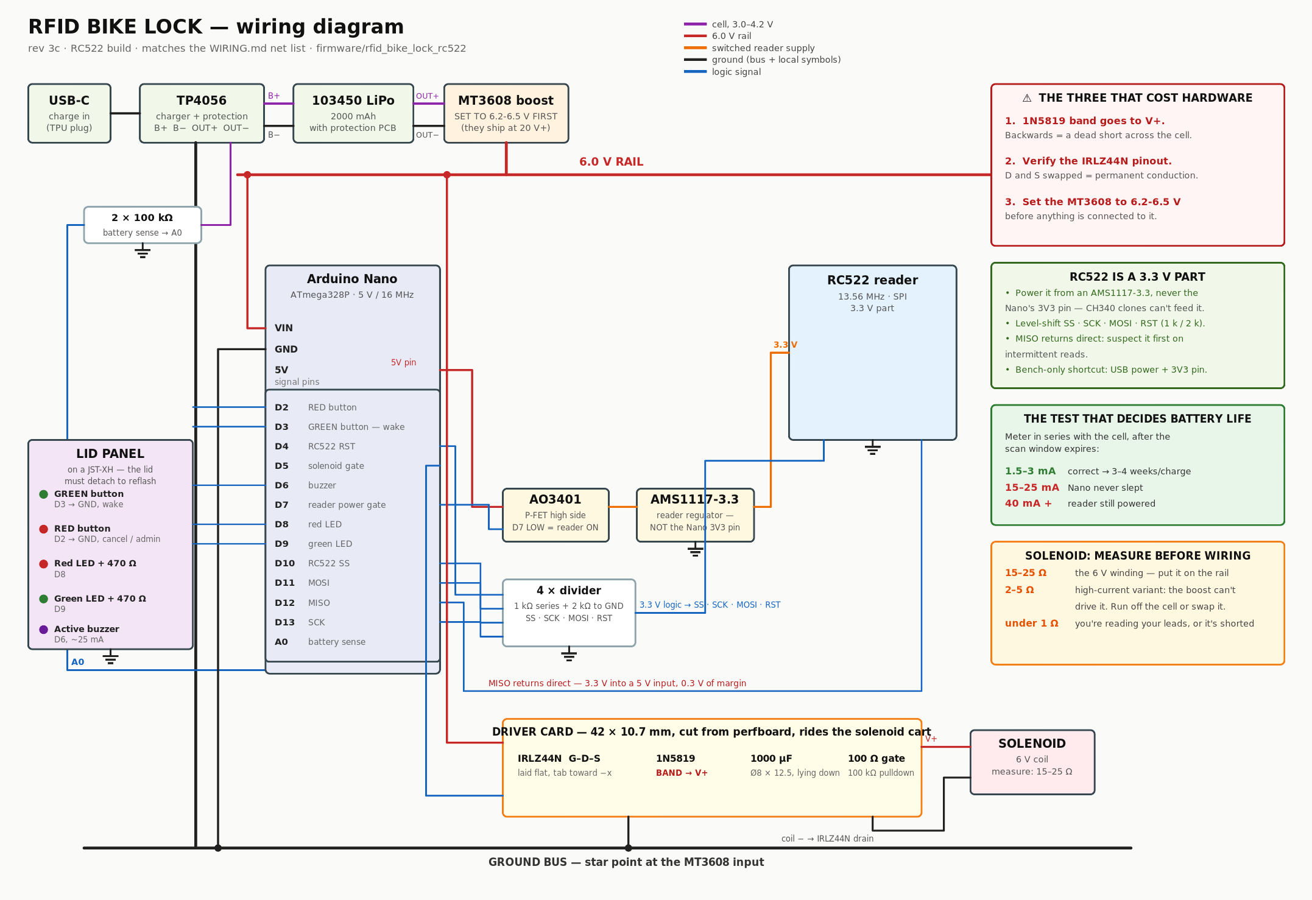
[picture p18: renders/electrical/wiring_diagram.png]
wiring diagram


*Full-size: [`renders/electrical/wiring_diagram.png`](renders/electrical/wiring_diagram.png) · vector:
[`.svg`](renders/electrical/wiring_diagram.svg) · regenerate with `python cad/wiring_diagram.py`*

Everything electrical for the rev 3c lock: what connects to what, why it is arranged that
way, the order to solder it in, and what to measure at each step. Mechanical assembly is in
[`ASSEMBLY_CNC.md`](ASSEMBLY_CNC.md); this file is the companion for the wiring.

Firmware referenced throughout: `firmware/rfid_bike_lock_rc522/` (RC522 build).

---

## 0. Know your parts before you wire them

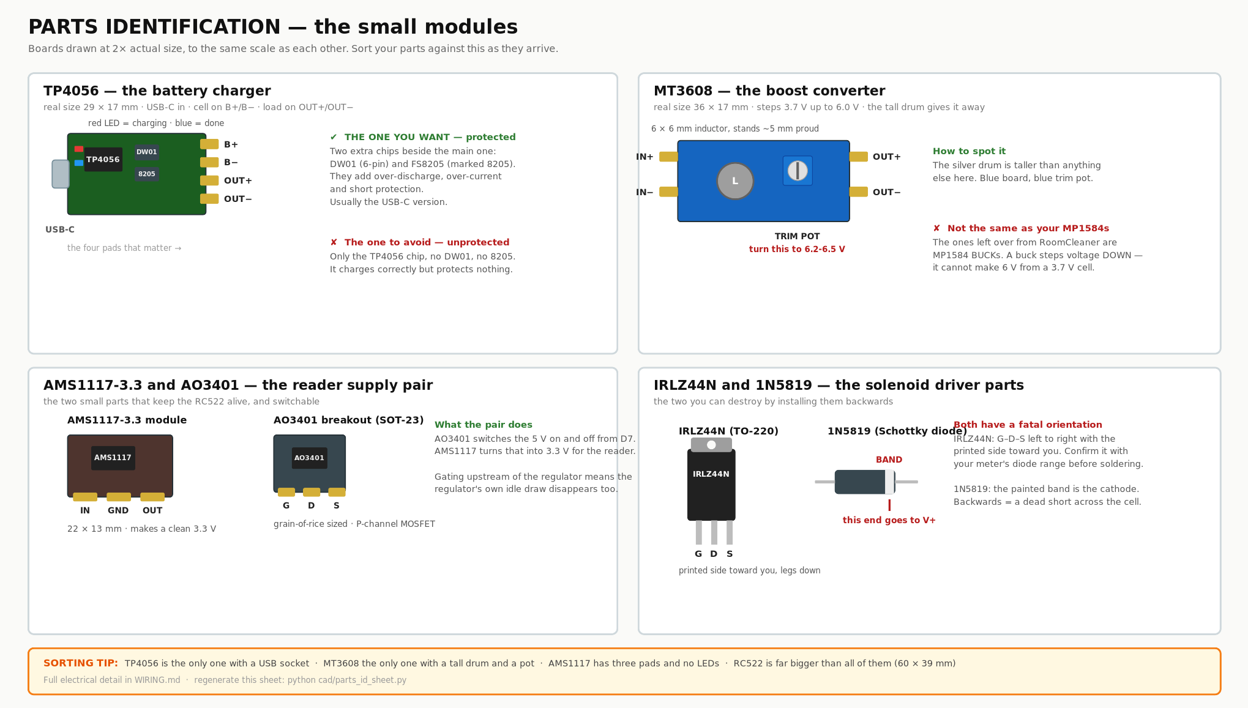
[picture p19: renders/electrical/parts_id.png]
parts identification


⚠️ **A 2S/3S charger is not a TP4056.** Boards sold as "2S 2A boost converter 8.4 V / 12.6 V /
16.8 V charging protection" charge **multi-cell packs**: 8.4 V is two cells in series, 12.6 V
is three, 16.8 V is four. This lock runs **one** 103450 cell that must never see more than
**4.2 V**. Putting a single cell on an 8.4 V charger drives it far past its limit — that is
the failure mode that vents and burns. If you have one of these, set it aside for a 2S
project and order a TP4056.

| | TP4056 (what you need) | 2S/3S boost charger (not this) |
|---|---|---|
| Charges | one cell to 4.2 V | packs of 2–4 cells to 8.4 / 12.6 / 16.8 V |
| Silkscreen | "TP4056" on the main chip | "2S", "3S", "8.4V", "12.6V" |
| Board | 29 × 17 mm, flat, two LEDs | larger, usually with an inductor |

---

## 1. Architecture — three power domains

```
   USB-C ──► TP4056 ──► 103450 LiPo (3.0–4.2 V)  ── the CELL domain
                              │
                              ├──────────────► MT3608 boost ──► 6.0 V  ── the RAIL domain
                              │                                   │
                              │                          ┌────────┴────────┐
                              │                          │                 │
                              │                    Nano VIN          solenoid +
                              │                   (AMS1117 → 5 V)         │
                              │                          │            IRLZ44N ◄── D5
                              │                          │
                              │                    AO3401 ◄── D7
                              │                          │
                              │                    AMS1117-3.3
                              │                          │
                              │                     RC522 3.3 V  ── the READER domain
                              │                                     (dead when D7 is HIGH)
                              └── 100 kΩ / 100 kΩ divider ──► A0
```

Why it is split this way:

- **The reader domain is switchable.** An RC522 idles around 15–26 mA, which would flatten
  the cell in days. D7 kills its supply completely between scans, and killing it *upstream of
  the regulator* means the regulator's own quiescent draw goes too.
- **The solenoid sits on the rail, not on the logic.** It shares the 6 V node with the Nano
  but has its own path back to ground so its 300 mA pulse does not travel through logic
  ground wiring.
- **The cell domain is the only place with real energy.** Everything downstream is fused by
  the cell's own protection PCB.

---

## 2. Complete net list

Every wire in the lock. If it is not on this list, it should not exist.

### 2.1 Power

| From | To | Wire | Notes |
|---|---|---|---|
| Cell + (red) | TP4056 **B+** | 22 AWG | JST-PH pigtail if the cell has one |
| Cell − (black) | TP4056 **B−** | 22 AWG | |
| TP4056 **OUT+** | MT3608 **IN+** | 22 AWG | |
| TP4056 **OUT−** | MT3608 **IN−** | 22 AWG | this is system ground, star point |
| TP4056 **OUT+** | 100 kΩ → A0 | 26 AWG | battery sense, top of the divider |
| A0 | 100 kΩ → GND | 26 AWG | bottom of the divider |
| MT3608 **OUT+** | Nano **VIN** | 22 AWG | 6.2–6.5 V |
| MT3608 **OUT+** | driver card **V+** | 22 AWG | solenoid supply |
| MT3608 **OUT−** | Nano **GND** | 22 AWG | |
| MT3608 **OUT−** | driver card **GND** | 22 AWG | separate wire, not daisy-chained through the Nano |
| Nano **5V** | AO3401 breakout **IN** | 24 AWG | reader domain feed |
| AO3401 **OUT** | AMS1117-3.3 **IN** | 24 AWG | |
| AMS1117-3.3 **OUT** | RC522 **3.3V** | 24 AWG | |
| AMS1117 **GND**, RC522 **GND** | system GND | 24 AWG | |

### 2.2 Signals

| Nano pin | To | Series part | Notes |
|---|---|---|---|
| D2 | RED button → GND | — | internal pullup; tap = cancel, hold 5 s = admin |
| D3 | GREEN button → GND | — | INT1, the **only** wake source |
| D4 | RC522 **RST** | 1 kΩ / 2 kΩ divider | see §3 |
| D5 | driver card **GATE** | 100 Ω | 100 kΩ pulldown on the card |
| D6 | buzzer **+** | — | active buzzer, ~25 mA |
| D7 | AO3401 **gate** | 10 kΩ pullup to 5 V | LOW = reader on |
| D8 | RED LED **anode** | 470 Ω | |
| D9 | GREEN LED **anode** | 470 Ω | |
| D10 | RC522 **SDA/SS** | 1 kΩ / 2 kΩ divider | |
| D11 | RC522 **MOSI** | 1 kΩ / 2 kΩ divider | |
| D12 | RC522 **MISO** | direct | reader drives this, see §3 |
| D13 | RC522 **SCK** | 1 kΩ / 2 kΩ divider | |
| A0 | battery divider | — | |

---

## 3. The RC522 voltage problem — read before wiring

This is the single most common way to kill an RC522, so it gets its own section.

**The module is a 3.3 V part.** Its VCC pin must see 3.3 V, and its logic inputs are rated to
3.3 V. The Nano is a 5 V part driving 5 V logic. Three consequences:

**a) Do not power it from the Nano's 3V3 pin.** On a CH340 clone that pin is either fed by a
tiny regulator good for ~50 mA, or on some clones it is not connected to anything useful at
all when the board is running off VIN rather than USB. The RC522 pulls up to 26 mA in bursts
and browns out. **Use a proper AMS1117-3.3 module** fed from the switched 5 V.

**b) Level-shift the four inputs.** SS, SCK, MOSI and RST are driven by the Nano at 5 V. The
cheap, reliable fix is a resistor divider on each: 1 kΩ in series, 2 kΩ to ground, giving
3.3 V at the module pin.

```
Nano D13 ──[1 kΩ]──┬── RC522 SCK
                   │
                 [2 kΩ]
                   │
                  GND        (same pattern for D10→SS, D11→MOSI, D4→RST)
```

Eight resistors total. A 4-channel level shifter module does the same job if you have one.

**c) MISO goes back direct.** The RC522 drives it at 3.3 V. The Nano's logic-high threshold
at 5 V supply is 3.0 V, so 3.3 V reads as HIGH — with only 0.3 V of margin. It works, and
essentially every RC522-on-Uno tutorial relies on it, but if you get intermittent read
failures after everything else checks out, this is the suspect.

**On the bench you can skip all of this** by running the Nano from USB 5 V and the RC522 from
the 3V3 pin, which is what most tutorials do. It survives because USB supplies plenty and the
runs are short. Do not carry that shortcut into the sealed box.

---

## 4. Which solenoid you got decides the wiring

**Measure the coil resistance with a multimeter before wiring anything.** Two leads, ohms
range, across the solenoid's terminals. What you read decides the circuit:

**What actually arrived: a Heschen HS-0730B, 6 V / 1 A / 5 N** (≈ 6 Ω). That sits between the
two rows below. It runs off the **6 V rail**: the MT3608's 2 A covers a 1 A output, and the cell
supplies ~1.9 A for the pulse — right at the 2000 mAh pack's 1C rating, fine for 300 ms but
worth trying a **150 ms** pulse (`SOLENOID_PULSE_MS`) once you see how hard it pulls. Running it
straight off the 3.7 V cell instead gives only 0.62 A, and force goes as current squared, so
about 40 % of rated pull — not enough.

| Reading | What it is | How to wire it |
|---|---|---|
| **15–25 Ω** | the 6 V / ~300 mA winding the design originally assumed | **Solenoid on the 6 V rail**, full rated force, boost barely loaded |
| **5–8 Ω** | the HS-0730B class, ~1 A at 6 V — **this is what you have** | 6 V rail, and expect ~1.9 A from the cell during the pulse |
| **2–5 Ω** | a high-current variant (1.5–3.4 A) | The boost **cannot** do this. Run the coil straight off the cell, accept ~60 % force, and expect the cell's protection to trip if it is a 3.4 A unit. Better: return it and get the 6 V one |
| **under 1 Ω** | you are measuring your leads, or the coil is shorted | re-check with the leads touching first, subtract that |

The rest of this document assumes the 15–25 Ω case.

**About the reservoir capacitor.** 1000 µF at 6 V holds about 1 mC of usable charge; the
300 ms pulse needs 90 mC. So the cap does **not** power the pulse — the boost does. The cap
is there to absorb the switching transient at turn-on and to keep the rail from dipping
sharply enough to reset the Nano. It is doing a real job, just not the one it is often
credited with.

---

## 5. The driver card

A 42 × 10.7 mm rectangle cut from your perfboard, which is about **16 × 4 holes** at 0.1"
pitch. It rides on the solenoid cart so the switching sits under 30 mm from the coil.

driver card

### 5.1 What goes on it

| Part | Placement |
|---|---|
| IRLZ44N | **laid flat**, tab toward the −x end, legs bent 90° into the board |
| 1N5819 | across the coil terminals, **band toward V+** |
| 1000 µF, Ø8 × 12.5 **or Ø10 × up to 20** | **lying down** along the card — there is 2.25 mm of headroom to the lid, so a Ø10 can also fits |
| 100 Ω | gate series, D5 to gate |
| 100 kΩ | gate to source (pulldown) |

### 5.2 Layout, row by row

Hold the card with the 42 mm dimension horizontal and 4 rows top to bottom:

```
row 1  ┌────────────────────────────────────────────┐
       │  V+ rail  ●━━━━━━━━━━━━━━━━━━━━━━━━━━━━●    │  ← V+ from MT3608, and to coil +
row 2  │   [1000 µF lying]        [1N5819 →|]       │
row 3  │   IRLZ44N flat:  G  D  S                   │  ← D to coil −, S to GND
row 4  │  GND rail ●━━━━━━━━━━━━━━━━━━━━━━━━━━━●    │  ← GND from MT3608
       └────────────────────────────────────────────┘
          [100 Ω] from D5 to G,  [100 kΩ] from G to GND
```

Build the two rails first as bare tinned-wire runs along rows 1 and 4 — they carry the pulse
current and a solder trace alone is not enough.

### 5.3 The two mistakes that cost hardware

1. **1N5819 backwards.** The band (cathode) goes to **V+**. Reversed, it conducts the moment
   you apply power: a dead short across the cell, through a Schottky diode that will not
   survive it. Check it twice; it is the one error with no warning.
2. **IRLZ44N pinout assumed.** Facing the printed side, legs down, it is **G–D–S** left to
   right. Getting D and S swapped puts the body diode across the supply, which conducts
   permanently. Confirm with the diode-test range before soldering.

---

## 6. Build order, with what to measure

Do not skip the measurements. Each one catches a specific failure before it can propagate.

### Step 1 — power chain alone, no logic

Wire only: cell → TP4056 → MT3608. Nothing on the output.

| Measure | Expect |
|---|---|
| TP4056 OUT+ to OUT− | cell voltage, 3.4–4.2 V |
| MT3608 OUT+ to OUT−, adjusting the pot | sweeps well past 6 V |
| Set it and re-measure | **6.2–6.5 V** (not 6.0: the Nano's regulator needs ~1.1 V of dropout) |

**Then power down before connecting anything.** An MT3608 shipped at 20 V+ will destroy the
Nano in the time it takes to notice.

### Step 2 — Nano alone on the rail

6 V to VIN, ground to GND. Nothing else.

| Measure | Expect |
|---|---|
| Nano 5V pin to GND | 4.9–5.1 V (its AMS1117 working) |
| Nano 3V3 pin | ignore this pin, we are not using it |
| Current into VIN | 15–25 mA with the sketch running, before sleep |

### Step 3 — reader domain

Add the AO3401 breakout, the AMS1117-3.3, the four dividers, and the RC522.

| Measure | Expect |
|---|---|
| AMS1117 OUT, D7 driven LOW | 3.25–3.35 V |
| AMS1117 OUT, D7 HIGH or floating | under 0.1 V — if it stays up, the P-FET is in backwards |
| RC522 SCK pin while idle | around 0 V; scope or meter on the divider midpoint reads ~3.3 V when driven |

Flash the firmware. Green button → chirp, `[wake]` on serial, fob tap prints a UID.

### Step 4 — solenoid stage

Add the driver card and coil. **Do this on a bench supply first if you have one**, current
limit 500 mA.

| Measure | Expect |
|---|---|
| Coil resistance, before wiring | 15–25 Ω (see §4) |
| Across the coil, idle | 0 V |
| Across the coil during the 300 ms pulse | 5.5–6 V |
| Rail during the pulse | should not dip below 5.5 V |

If the Nano resets when it fires: grounds are not properly common, or the driver card's
ground goes through the Nano instead of back to the MT3608.

### Step 5 — sleep current, the real test

Meter in series with the cell, sketch running, let the scan window expire.

| Reading | Meaning |
|---|---|
| **1.5–3 mA** | correct — MT3608 quiescent plus the Nano's leaks |
| 15–25 mA | the Nano never slept. Usual causes: a button wired to the wrong pin so D3 is held low, or `#define DEBUG` left in keeping serial alive |
| 40 mA+ | the reader is still powered — D7 logic or the P-FET orientation |

At 2.5 mA the 2000 mAh cell lasts roughly **three to four weeks** per charge. That number is
the whole reason the reader is gated.

---

## 7. Harness, physically

**On the bench, cut nothing.** Use kit jumpers at whatever length they come. The one rule:
keep the five **SPI wires under ~20 cm** — the RC522 goes flaky on long unshielded runs, and a
"reader not found" caused by wire length is miserable to debug.

**In the box**, computed from where each part actually sits in the model (straight-line distance
× 1.4 for routing, + 25 mm for slack and stripping, rounded up):

| Run | Cut to | Gauge |
|---|---|---|
| Battery → TP4056 | 150 mm | 22 AWG |
| TP4056 → MT3608 | 60 mm | 22 AWG |
| MT3608 → Nano VIN/GND | 40 mm | 22 AWG |
| MT3608 → driver card V+/GND | 50 mm | 22 AWG |
| **Driver card → coil** | **50 mm — keep it short** | 22 AWG |
| Nano D5 → driver gate | 50 mm | 26 AWG |
| Reader → Nano, 7 wires | 130 mm | 26 AWG ribbon |
| Nano → buttons (lid loop) | 150 mm | 26 AWG |
| Nano → LEDs (lid loop) | 160 mm | 26 AWG |
| Nano → buzzer (lid loop) | 120 mm | 26 AWG |

The three lid-loop runs carry **+70 mm beyond the computed length** so the lid can be lifted off
and set beside the box with everything still connected. That is also why they land on a
**JST-XH** rather than being soldered direct — the lid has to come off to reflash.

Only two runs are length-sensitive: **driver card to coil**, because it is the flyback loop and
length degrades the clamp, and the **SPI bundle**. Everything else is forgiving.

Leave a service loop on the battery leads; the cell is the part most likely to be replaced.

## 8. Failure table

| Symptom | Check in this order |
|---|---|
| Nothing at all, no serial | MT3608 output voltage; then VIN vs 5V pin |
| Serial works, reader not found (fast red ×5) | SS and RST pin assignment · module header actually soldered · 3.3 V present at the module · dividers not swapped |
| Reader found, never reads a fob | antenna side facing the tag · fob is 13.56 MHz not 125 kHz · MISO margin (§3c) |
| Reads on the bench, not in the box | distance to the lid · anything metal near the antenna · reader supply sagging under the box wiring |
| Solenoid silent | coil resistance · gate voltage at D5 during the pulse (should be ~5 V) · MOSFET pinout |
| Solenoid weak | wrong winding (§4) · rail dipping · plunger binding mechanically, not electrical |
| Nano resets on unlock | grounding topology · reservoir cap missing or on the wrong node |
| Battery drains in days | sleep current test, §6 step 5 |
| Charging never completes | TP4056 has no load sharing — charge with the lock asleep |

---

## 9. Honest gaps

- **The firmware has never run on hardware.** Section 6 is the first time it will.
- **No cable-state sensor.** An authorized tap pulses the solenoid whether or not the cable
  head is in the latch. Harmless, but the lock cannot tell you it is locked.
- **No load sharing on the TP4056.** Charging while awake confuses termination. A v2 fix is a
  load-sharing P-FET between charger and load.
- **UID matching only.** UIDs are cloneable with cheap hardware. Real security needs
  challenge–response, which needs a different tag type and more firmware.

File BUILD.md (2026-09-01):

# BUILD.md — the end-to-end build workflow (v0.7)

This is the answer to "can the BOM be assembled into a workflow where the entire
thing works?" — **yes, with the additions in §1**, following the sequence in §3
exactly. Every BOM item maps to a step; every step names its tool and access;
electrical bring-up checkpoints are interleaved so failures surface at the
cheapest possible moment. Produced from a 4-lens machine-assisted audit (BOM
mapping, wiring harness, build-order simulation, firmware bring-up) against the
gate-verified v0.7 geometry.

## 1. What the BOM was missing (now added — order these too)

| Item | Why it was missing | Resolution |
|---|---|---|
| **Cable head (Phase-1)** | The core latch part only existed as a Phase-2 "shop job" — nothing to lock on first build | BOM 23k: bench-mule square tang stock (steel flat bar) for Phase 0 + the round grooved head as a TAMU-shop lathe job (Ø10 head, square-flanked groove at Ø6.6, Ø5 stem swaged to the cable). Modeled as `89_mock_cable_head` (latched position, gate-checked) |
| **Ejector spring seat** | Its documented home ("under the bore floor") was consumed by the v0.6 closure screw channel | No new geometry needed: the spring sits **in the bore, on the closure screw's washer** (z30 ledge), Ø9 × ~15 free length, compressed ~5 mm by the seated head. Dropped in AFTER the consumer screw. BOM 21 re-spec'd |
| **JST connectors** | Promised throughout DESIGN, never on the BOM | BOM 16b: JST-XH kit (2/3/4-pin) + note: factory-protected 103450 cells ship with **JST-PH 2.0** pigtails — buy one PH pigtail or re-terminate |
| **Driver card stock** | The driver stage had no defined board | Cut a 42×10.7 card from the same 4×6 cm perfboard (BOM 16) |

## 2. The v0.7-final electrical architecture (one load-bearing change)

The audit found the solenoid driver stage sat in the bay, **150–200 mm of wire
from the solenoid** — 5–7× the design target, degrading the flyback clamp and
defeating the reservoir cap. Fixed: **all driver electronics live in the pod**
on a 42×10.7 card on the pedestal-cart’s −Y platform (v0.8.2: two Ø8 cart bosses, short M3 heat-sets)
(bosses at x66/x96, 2× M3 ST), components facing up (IRLZ44N flat, AO3401,
1N5819, Ø8×12.5 cap lying, divider) — **<30 mm to the solenoid**, and the bay
perf rack is deleted. The bay now holds only the cell + TP4056.

**The spine carries exactly 2 conductors** (TP4056 OUT+ / OUT− up to the
MT3608), 22 AWG, pulled bare through the Ø7 feed hole (connectivity
machine-verified) and connectorized in the pod. The battery-sense divider taps
OUT+ pod-side — no extra crossing. Nothing crosses the door hinge.

## 3. Bench build sequence (tool · access per step)

**Stage A — parts + inserts (open bench)**
1. Print 14 parts (+ TPU liners/shim); turn or order the hinge rod (BOM callouts; zero-lathe fallback: plain Ø4 rod + a cap both ends).
2. Press the heat-sets (see BOM 23a–23f; v0.8.2 adds 2× short M3 in the cart platform bosses): 4× M3 pod-rim bosses (soldering iron, straight down through the open pod top) · 2× M3 into TP4056-block/drum-web from below · 2× M2.5 pedestal tower top · 1× short M3 into the door pad’s TOP face (v0.8: all-M3) (door open, flange-up). **Gate: VERIFY JF-0530B hole spacing (24?) BEFORE the M2.5 inserts** — the cart is a minutes-long reprint.

**Stage B — pod electronics (all straight-down access; MUST finish before the lid ever goes on)**
3. Nano into the pod wall recess (edge-standing, pins trimmed flush, USB end at x39–47) → `nano_clamp` bar onto the crown bosses, 2× M3 ST flat.
4. Pedestal cart onto the pod pads — 2× M3 pan through the tower access holes (heads hidden under the solenoid later).
5. Build + solder the driver card (42×10.7): IRLZ44N flat, AO3401, 1N5819, cap lying, divider → onto the cart platform bosses (x66/x96, y−7.25), 2× M3 machine into the short heat-sets, straight down — do this BEFORE the cart goes into the pod if you prefer bench access; the cart+driver+solenoid drop in as one module.
6. **MT3608 onto the tower end-posts BEFORE the solenoid** (0.3 mm design clearance between them; clone solenoid width varies 13–16). Set 5.00 V under load *now*, on the bench.
7. Solenoid onto the tower — 2× M2.5×8 machine into the inserts. File the plunger's 45° ramp; **trim the plunger tail to end at x98** (machine-asserted against the wake button — untrimmed it collides).
8. ⚡ **Checkpoint 1**: bench-power the pod cartridge cluster from a 5 V supply — solenoid pulse test (300 ms via D5), MT3608 rail check, before anything is enclosed.

**Stage C — bay (independent of Stage B)**
9. LiPo stands on edge at the +y wall (lead corner at the strain-relief notch); TP4056 slides −X into its cradle until the USB-C registers in the wall port.
10. ⚡ **Checkpoint 2**: charge test through the wall port; verify OUT+/− feeds (fail-secure architecture depends on OUT wiring, not cell wiring — DESIGN §8).

**Stage D — marry bay to body, then harness**
11. Bolt the loaded bay to the body — 4× M4×12 from inside the open clamp bore (heads sub-flush). **This must precede spine wiring** — the spine window halves only align once bolted.
12. Pull the 2 spine conductors bare (bay → window → raceway → feed hole → pod), connectorize pod-side (JST-XH), leave the documented service loop bay-side so dropping the hatch-tray never strains the cell leads. Lay the pair in the open raceway → `spine_cover`, 2× M3 ST flat.
13. Hatch-tray on — 2× M3 machine flat into the block/web inserts, countersunk external.

**Stage E — lid (open bench, lid detached)**
14. PN532 onto the drop bosses — 4× M2.5 **nylon** + captive 1 mm foam pad (never steel: the antenna loop wraps the board perimeter). Button through its panel hole (own nut); LEDs press-fit. Dress the 4-wire lid loop (I2C + switched 5 V) with lift-slack + JST so the lid fully detaches.
15. ⚡ **Checkpoint 3**: full-system smoke test, lid resting in place: wake → scan window → tag read → solenoid pulse → sleep current. **Reflash access = lid off** (4 screws), not the hatch — the Nano lives in the pod.
16. Lid on — 4× M3 machine flat into the rim inserts, flush.

**Stage F — mechanical completion**
17. **Liners stay OUT until after drilling.** Door closed + clamped: drill the hinge bore Ø4.2 through all 8 knuckle segments (measure the rod first; 2-stage drill; deburr 16 mouths). Insert the rod tail-first from the front; head seats flush; `hinge_cap` + 1× M3 ST flat.
18. Slide the TPU liner keys in from the front face to the blind stop (click past the bump); halves captive, no glue.
19. Donor spool into the drum (bay bolted or not — clearance-verified either way; off-body is easier for winding). **Improvise per donor** (nothing is modeled — known gap): spring outer anchor to the ring wall, spool rotation on the cover's Ø10 hub, hold preload before the cover traps it. Route the cable out the snout; swage the end stop; swage the head (or bench-mule tang) on the working end. `spool_cover`, 3× M3 ST flat, flush.
20. Ejector spring drops into the bore later — **after** the consumer closure screw exists (on-bike step): screw → washer → spring → done.

**Stage G — on-bike (the consumer step)**
21. Open door → press onto the down tube → swing shut → ONE M3×10 machine-flat down the latch bore (v0.8) → drop in the ejector spring → enroll the master fob (first boot). Locked cable head now covers the screw.

## 3b. Print orientations (v0.8.3 — matches the `--dfm` scan table in the CAD)

Run `python cad/bike_lock_cq.py --dfm` for the live overhang report. Declared orientations
(`DFM_ORIENT` in the CAD is the single source of truth):

| Part | Orientation | Supports |
|---|---|---|
| body | pod rim up (as modeled) | yes — under shell + knuckles |
| door | seam face down | yes — under knuckles + bore ceiling |
| bay_module | cover/rabbet face down | yes — brick overhangs |
| lid | underside on plate | minimal — the 4 PN532 drop-bosses start 0.3 above the plate |
| pedestal_cart | flat z32 bottom on plate (v0.8.3 flush fix) | none |
| bay_hatch, spine_cover, nano_clamp, hinge_cap, usb_plug | flat | none |
| spool_cover | as modeled **with a raft** — its 3 nesting pads hold the disc 0.8 off the plate | raft |
| liners + shim | TPU: ON END (vertical) - the profile is a constant-section extrusion, so every layer is the same C-with-fins slice: no overhangs, perfect fins. 5mm brim, seam on the base ring, 20-25 mm/s | none |

## 4. Honest remaining gaps (will not stop the build, must not be forgotten)
- **Donor spool anchoring is unmodeled by design** (donor-dependent) — step 19 is the only improvised step in the workflow.
- **VERIFY-on-arrival gates**: solenoid hole spacing + width (13–16!), PN532 corner holes + dims, MT3608 true height, TP4056 USB overhang, insert brand dims, ST flat-head angle (80/90°), Nano USB variant, plunger Ø for the 6.5 ream decision, LiPo protection-PCB bump.
- **Read-range sanity check**: the Nano now sits ~10 mm below the PN532 keep-out column — verify range on real hardware (move to the far pod end is the fallback).
- Firmware is complete but has never run on hardware; Checkpoints 1–3 are the earliest failure surfaces.

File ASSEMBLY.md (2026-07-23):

# Assembly Plan & DFM/DFA Audit

> **v0.8 FASTENER STANDARD (supersedes the per-step screw callouts below):** every
> threaded joint is now an **M3 machine screw into an M3 brass heat-set insert** — press
> **all** inserts on the open bench before assembly. Two carve-outs, both forced by an
> external part: the **solenoid** stays **M2.5** (its own tabs are drilled M2.5), and the
> **PN532** stays **M3 nylon** into printed bosses (brass at the antenna corners kills
> read range). The closure screw is now a **short M3 heat-set** (Ø4.0×L3.8) in the shallow
> door pad; the bay screws are **M3 socket-cap into inserts** (were M4 self-tap). Insert
> tally: **~19 full M3 (Ø4.1×6.5) + 3 short M3 (Ø4.0×L3.8) + 2 M2.5 (Ø3.6×4.5)**; PN532 = 4 nylon, no insert.
>
> **v0.7 FINAL: the authoritative bench build sequence now lives in [BUILD.md](BUILD.md)**
> (4-lens audited: BOM mapping, harness, build-order simulation, bring-up checkpoints).
> Key corrections vs the tables below: the Nano edge-stands in the POD wall recess
> (nano_clamp on crown bosses - reflash = lid off, NOT the tray); ALL driver
> electronics sit on a 42×10.7 card **on the pedestal-cart's −Y platform (v0.8.2 Option C —
> short M3 heat-sets in the cart bosses, driver+solenoid+cart pull as one module)**; the
> bay perf rack is deleted (the spine carries only 2 conductors); MT3608 mounts BEFORE the
> solenoid (0.3mm clearance); liners install AFTER hinge drilling (swarf); the
> spine is wired AFTER the bay is bolted (window halves align only then); the
> ejector spring drops into the bore AFTER the consumer closure screw.
>
> **v0.8.3 weatherproofing steps (do these at the marked points in BUILD.md):**
> 1. Before the lid goes on (BUILD step 16): lay **1 mm EPDM foam tape** (BOM 30a) on the
>    pod rim, holes punched at the 4 screw bosses — the 4 lid screws compress it into the
>    water stop behind the cosmetic reveal gap.
> 2. When the LEDs go in: seat them from below, then pot the domes + the two Ø3.3 lid
>    holes with **clear RTV silicone** (BOM 30b). Fill from the top recess; wipe flush.
> 3. At solenoid install: film of **silicone grease** (BOM 30c) on the plunger and the pin
>    channel mouth — the latch-bore weep drains the rain, the grease keeps the residue from
>    freezing the pin.
> 4. After charging, always press the **`usb_plug`** (TPU, printed) back into the bay USB
>    port — it's the only thing between wheel spray and the TP4056.
> 5. Do NOT plug the two small weep holes (latch-bore floor, drum-ring bottom): they are
>    drains, not defects.

Design-level review of whether the design can actually be put together easily.
Verdict at v0.2: sound skeleton, three real gaps. **v0.3 (the CadQuery restructure)
implements every fix in §3** plus the modular split: separate drum module bolted from
inside the bore, and all interior furniture as pad-mounted cartridges.

## 1. Intended assembly sequence (v0.6)

Part set: 12 printed parts + 1 lathe-turned hinge rod (13 items; `end_plug` ×2 is
deleted — no more glued joints anywhere in the build). New parts vs. v0.5: `hinge_rod`,
`hinge_cap`, `spine_cover`.

| Step | Operation | Access | Fasteners |
|---|---|---|---|
| 1 | Print all 12 parts; lathe the hinge rod (one op from Ø6 303 stainless bar). Install **all** heat-set inserts on the open bench: 4× M3 into the lid's pod-rim bosses (driven from the open pod top, before the lid goes on); 2× M3 into the bay module's TP4056 block and drum web (driven from below, before the hatch/tray goes on); 2× M2.5 into the pedestal cartridge's tower top (for the solenoid); 1× short M4 into the door's closure pad, from the pad's **top** face with the door open and flange-up on the bench | open bench, various faces per insert | 6× M3 (Ø4.1×6.5) + 2× M2.5 (Ø3.6×4.5) + 1× M4-short (Ø5.6×L3, VERIFY sourcing) heat-sets — 9 total |
| 2 | Bolt the pedestal cartridge onto the body's pod-rim pads: screws drive down through the tower's Ø6.5 access holes, so heads land on the pad boss and end up hidden once the solenoid covers them | from above, through the tower, open pod | 2× M3 pan self-tap |
| 2b | Solenoid onto the pedestal tower. **VERIFY the real unit's mounting-hole spacing before installing the M2.5 inserts** — `sol_hole_dx` is drawn at 24 mm; if the measured unit differs, reprint the pedestal cartridge (a minutes-long print, not a redesign) rather than force the fit. Bench-test the latch action before moving on | open bench or in place | 2× M2.5×8 machine, into brass heat-sets |
| 3 | Plunger nose = locking pin (see §3.1, unchanged) | — | none |
| 4 | LiPo cell into the bay: it stands **on edge** against the +Y wall — the block face, one retaining rail, and the wall bound it. No zip-tie pass-unders anymore | from above, open bay | — |
| 5 | TP4056 into its front-wall slot; USB-C self-aligns to the port | from above | none (pocket) |
| 6 | Hatch-tray build and close: zip the Nano (mounted **diagonally** — the service window is 40.5×29.5), MT3608, and perfboard to the tray's anchor grid. **Leave a documented service loop in the cell leads** before closing — dropping the tray for service must never strain the battery wiring. Close the tray onto the bay, countersunk on the **external** face | slides in from the front, then closes from outside | 2× M3 machine flat, into brass heat-sets from step 1 |
| 7 | Harness: lay the wire run **into** the open wire-spine raceway (it's an open lay-in channel now, not a sealed conduit you fish blind) and screw the spine cover down over it. Bay↔pod feed-hole path is unchanged | from above, open raceway | 2× M3 self-tap flat, countersunk |
| 8 | PN532 into the lid pocket: nylon screws through the board's corner holes into the lid's drop-bosses (no steel near the antenna loop, which wraps the full board perimeter), plus a captive 1 mm foam pad over the antenna face — pressure-fit, **no adhesive**. If a clone board lacks the corner holes, print the corner-clip fallback onto the same bosses. Then button + LEDs; plug the lid's JST service loop | open bench | 4× M2.5×8 NYLON machine |
| 9 | Lid on | from above | 4× M3 machine flat, into rim heat-sets from step 1 |
| 10 | Donor spool into drum module, cable out the snout, wind preload | open bench (module off the bike!) | — |
| 10b | Spool cover on, re-clocked so one screw sits on the vertical axis (90/210/330°) | open bench | 3× M3 self-tap flat, countersunk |
| 11 | Bolt the loaded bay module (drum + spool + electronics + tray) to the body — screws drop through the clamp bore wall | from inside the open clamp | 4× M4 pan self-tap |
| 12 | Hinge: door closed and clamped against the body, **drill** the Ø4.2 finished bore through all knuckles — 8 segments, each ≤14 mm, no deep-hole drilling. Measure the actual rod OD first and pick a drill for 0.15–0.2 mm diametral clearance. Deburr all 16 mouths. Insert the hinge rod **tail-first from the front**, seat the integral head in its front counterbore, fit the hinge cap over the tail (0.5 mm axial float) and drive its screw into the shell end face. **No glue anywhere in this joint** | door closed, end faces + through-bore | 1× M3 self-tap flat, countersunk |
| 13 | On the bike: open door, press onto the down tube, swing shut, lip engages, ONE M4 down the latch bore (magnet-tip 2.5 mm hex) | top | 1× M4×8 low-profile socket + washer |

Steps 1–12 are the factory build; step 13 is the only thing the consumer ever does.
Steps 1–11 are top-down or open-face bench operations. Step 12 is not blind — it's a
through-drill on an assembled, clamped pair of halves with full visual/tactile access
at both ends — but it is a machining step, not a snap-together one, and it's the last
factory operation before the unit ships. Step 13 remains the only genuinely blind
fastener (one screw, driven down a bore you can't see the bottom of) and is the
security feature working as intended — see §4 and DESIGN.md §7 for what "intended"
now honestly covers.

## 2. What already passes DFA

- Single assembly direction (top-down into the open pod); no simultaneous-hold operations.
- Modules connect by JST — any board swaps without soldering; lid tethers by a plug.
- Battery/cell reachable by removing the hatch/tray's 2 screws — no soldering, no glue,
  and the service loop in the leads means dropping the tray can't strain the wiring.
- Fastener variety, by BOM (v0.6): M4 ×5 (1 closure + 4 bay, pan self-tap), M3 ×14
  (6 machine-flat into heat-sets: lid 4 + hatch 2; 6 self-tap flat: spool 3 + spine 2 +
  hinge cap 1; 2 pan self-tap: pedestal), M2.5 ×6 (2 machine into heat-sets: solenoid;
  4 nylon machine: PN532), plus the one-piece hinge rod and its screwed cap. Every
  joint is a heat-set-and-machine-screw or a direct self-tap — no glue anywhere.
- The one awkward fastener (bore-bottom M4) is deliberate — it's the tamper defense,
  and as of v0.6 it actually reaches its insert (D1/D2 fixed the broken screw path
  and insert pocket — see §8).

## 3. Gaps found — ✅ all implemented in CAD v0.3 (CadQuery)

1. **Plunger-as-pin (deletes the worst subassembly).** The separate Ø4 pin needed a
   coupling to the plunger, a spring seat, and a retaining clip inside a cramped channel —
   all unspecified. Change: the JF-0530B's own Ø6 plunger becomes the locking pin: file a
   45° ramp on its nose, widen the boss channel to Ø6.4 and the cable-head groove to
   ~6.5 mm, use the solenoid's included return spring. Zero added parts, self-aligning.
   *(Fallback if measured plunger force disappoints: revert to the separate-pin design,
   but then the coupling must be fully drawn before printing.)*
2. **Two short hinge pins, not one long one.** A 150 mm pin threaded through ~10
   interleaved knuckles plus the spool cover can't be aligned by hand. Change: ~55 mm
   pins inserted from each end face (knuckle spans already leave the middle empty),
   entry holes capped with glued printed plugs — which also hides the pin ends from view
   and from tampering.
3. **Card-edge pockets for TP4056 and MT3608.** Both boards currently have no mounts, and
   the TP4056's USB-C port must land flush in the rear-wall slot. Printed slide-in
   pockets fix retention and port alignment in one feature. Also: 4 corner posts (or clip
   tabs) for the PN532 on the lid underside; side rails + foam pad for the Nano.
4. **Fastener standardization:** all M3 = self-tap into 2.6 mm pilots (drop the drum-rim
   heat-set inserts); heat-set stays only for the M4 closure.
5. **Build-guide notes:** magnet-tip long hex key for the bore screw; thread the cable
   before winding spring preload.

### v0.7 addendum — tray cartridges
Steps 4-6 refine to: (i) screw the `nano_sled` and `shelf_cart` to the tray (4x M3x10
ST flat from the external face); (ii) zip the Nano to the sled (pins TRIMMED flush),
seat the cut 40x29 perfboard on the shelf pegs; (iii) TP4056 slides -X under the bay
cradle noses until the USB-C registers in the wall port; (iv) the cell stands on edge
against the +Y wall. Reflash = drop the tray, plug in on the bench - no in-situ USB
access needed.

## 4. Security note recorded during the audit

v0.6 status (full rewrite — see DESIGN.md §7 "Security analysis — honest version" for
the complete analysis; a judge finding forced that section's rewrite because its old
"every other seam is captive" claim is false): four fastener groups are externally
removable on the locked, closed bike — the lid (4× M3), the hatch/tray (2× M3), the
spine cover (2× M3), and the hinge cap (1× M3). Consequences:

- Removing the hatch or the spine cover exposes the solenoid's drive leads — a 5V
  source is a non-destructive path to actuate the latch without going through the app.
- Removing the hinge cap lets the rod slide out the front (the O6 head cannot pass the O4.2 bore, so it exits head-first from its front counterbore); the housing detaches from the
  clamp. The bike stays cable-tethered (the clamshell is still closed around the tube),
  but the lock body itself comes off.

This is the same class of finding as the v0.5-accepted lid→plunger exposure and is
accepted on the same basis: this is a prototype, and the owner has signed off on
"reasonable outward screws OK for now." It is not accepted silently — it is the
documented state, not an oversight.

Production mitigation list (now covering all four seams, not just the lid): one-way or
security-drive fastener heads, or staking, on the lid, hatch, spine cover, and hinge
cap; potted or sleeved solenoid drive leads so they can't be tapped from outside;
hidden lid fastening (already on the CAD TODO list — same item as before, now with a
concrete reason and three siblings).

## 5. Print plan (v0.3)

- The latch boss stays integral to `shell_right` (cable load path + hidden closure screw),
  but the drum is now its own zero-support module bolted from inside the bore — the shell
  print drops from ~20 h with a support forest to a clean pod-up print.
- Full per-part orientation/material table in `cad/README.md`. Cartridges are minutes-long
  prints, which is the point: all four VERIFY dimensions live in them.

## 6. v0.4 "slim top" delta (current CAD)

The sequence above still holds with these substitutions:

- Steps 4–6 happen **in the bottom bay on the bench**: LiPo into its printed frame
  (rear tunnel), TP4056 into its slot with the USB-C landing in the front-wall port,
  Nano/MT3608/perfboard zip-tied to the floor anchor grids. Tunnels close with two
  copies of the shared `bay_hatch` part (4× M3 each).
- The harness runs front↔rear through the bay's corner duct, then up the **wire spine**
  on the right shell into the pod (fish it with a pull wire before closing hatches).
- Step 11 bolts the whole loaded bay (drum + electronics) to the right shell — same
  4× M4 from inside the open clamp.
- The top pod now receives only the pedestal cartridge + solenoid; PN532/button/LEDs
  stay on the lid as before.
- Spool service = unbolt the bay (the cover can't slide out past the rear tunnel
  in place). Cam-lock backstop deleted (DESIGN.md §8 note).

## 7. v0.5 "spine + door" delta (current CAD) — consumer install achieved

Assembly review of v0.4 in SolidWorks found it could not be installed (pod/bay blocked
both the door swing and the tube entry). v0.5 restructures around three kinematic rules
(DESIGN.md §6.6) and adds **automated verification**: every `--sweep` run rotates the
door 0–110° against body+bay+lid and asserts zero interference, plus an entry-corridor
check on every build. Current status: **both PASS at 0.00 mm³.**

Changes to the sequence: the factory (you) still bench-builds everything; the CONSUMER
only ever does step 13 (open door, close on tube, one screw). Parts renamed:
`shell_right` → `body`, `shell_left` → `door`. The bay is a right-side brick (y 7–48)
with the slim Y-axis drum (Ø68×32) behind it; one hatch; spool cover faces outboard
(spool serviceable in place again). Latch line moved to y +10; the door carries flange
+ lip that engage through swept pockets.

## 8. v0.6 "no-glue rebuild" delta (current CAD)

A full defect sweep (D1–D12, machine-confirmed by the new `--gaps` min-distance probe
and an extended `--sweep` whose moving set is now door+liner_left against *all* other
parts — the old body+bay+lid-only sweep is what let D10 hide) found that most of the
housing's fastened joints either couldn't be assembled at all or weren't fastened
correctly. The kinematic rules from §6.6 are untouched; the sequence above (§1) is the
rewrite. What actually moved, in build order:

- **Step 1 grew from one insert to nine.** v0.5 needed a single M4 insert for the
  closure; v0.6 needs 6× M3 + 2× M2.5 + 1× M4-short, because D3 (lid), D4 (spool
  cover), D6 (hatch), and D12 (pedestal/solenoid) all turned out to be missing- or
  wrong-fastener defects, not just missing-hole ones. Doing all of them in one bench
  pass, before anything else is bolted on, is the only way to keep the build linear.
- **The closure screw path is fixed, not just re-specified.** D1 and D2 meant the
  v0.5 "ONE hidden M4" in step 13 physically could not be driven — the clearance hole
  hit the wrong z-segment and the insert pocket punched through the flange. The pad
  geometry, insert, and screw are new; step 13's *description* is unchanged because
  the consumer-facing action never changed, only the mechanism it now correctly drives.
- **Pedestal and solenoid split into two verified operations.** D12 found the pedestal
  attach holes and the solenoid mounting holes only 1 mm apart (68/94 vs. 69/93) —
  effectively merged into one hole. The attach pads moved to 76/86, giving each a clear
  ~7 mm to its nearest solenoid hole, and installing the solenoid's own inserts now
  waits on a VERIFY of the real unit's hole spacing.
- **The battery mount changed shape, not just fastening.** D11: the old flat-frame
  LiPo pocket and the TP4056 block occupied the same floor real estate — the cell
  could never have fit as drawn. It now stands on edge against a wall it can't collide
  with.
- **The hatch became a real, correctly-fastened service joint.** D6: it used to cover
  a solid floor with no pilots and heads that stood proud outside. It's now a
  removable component tray, with heads flush on the external face, threading into the
  inserts placed in step 1.
- **The spine went from a sealed, blind-fished conduit to an open lay-in raceway with
  a screwed cover** (owner request) — step 7 no longer starts with "fish it with a
  pull wire."
- **The hinge is one rod, not two glued-pin joints — this is the biggest sequence
  change.** D7 (glued plugs, no axial retention) is gone. Step 12 used to be
  glue-and-wait at each end face; it's now a single measured drill-through (Ø4.2,
  8 segments ≤14 mm, pick the bit off the actual rod OD) followed by a tail-first
  insertion and a *screwed* cap with a thermally-sized float. No adhesive appears
  anywhere in the v0.6 sequence.
- **PN532 mounting lost its foam tape.** Nylon screws into drop-bosses (steel would
  sit inside the antenna loop) plus a captive, non-adhesive foam pad.
- **Step 13's text is unchanged** — one M4×8, consumer-only — but see the closure-path
  point above: in v0.5 that step described a screw that could not reach its insert.

Net effect: 12 printed parts (was 13 — the two glued end plugs are deleted) + 1 lathe
rod, zero glued joints, and every removable fastener now has somewhere real to bite.
The security cost of that serviceability is in §4 and DESIGN.md §7.

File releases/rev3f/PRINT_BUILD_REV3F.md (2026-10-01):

# VELOX rev 3f — printable prototype, spool deferred

This supersedes the rev 3e **printing and electronics-mounting** instructions. Use the rev 3f STEP/STL set with `cad/cnc_casing_cq.py --profile print`. Do not mix its 2 mm taller A1/A2/window/bushing with rev 3e or the old v0.8.3 lineage. This is a prototype geometry release pending printer calibration and delivered-component fit; it is not a security or machining release.

## What changed

- A real, separate **electronics_cradle** now provides the solenoid's two supports, locating stops, driver-card shelf, Nano locating rails, charger edge guides and elevated boost shelf. Four M2×5 pan-head screws attach it to A1. Purchased-component references no longer contain pretend mounting furniture.
- The reader/battery table is still called **ref_tray**, but it is a printable part. Two M3×6 pan-head screws now attach it to A1; it has battery-strap space and reader-strap slots.
- Eleven **2.5 mm × 0.7 mm retention ties**, with assumed **4×4×3 mm lock heads**, are modeled in the assembly: coil×1, Nano×1, charger×1, battery×2, reader×2, driver×2, boost×2. Use ties long enough for each loop (coil lengthwise loop >83 mm before its lock head, reader perimeter >100 mm): **150 mm minimum length** is the starter specification, or longer trimmed. Measure your actual tie width/thickness/head; these are procurement assumptions.
- A1 has shallow open floor channels for the battery, Nano and charger straps. Its interior is **26 mm high**, 2 mm taller than rev 3e, so the boost shelf and ties have clearance. Nano moves +1.5 mm in Y; driver moves +0.6 mm; boost moves +1.5 mm in Y and rises to z51.7. Latch, coil axis, main floor and hinge remain at their previous positions.
- A2 and A4 have actual **90°** countersinks. The audit measures the conical faces rather than trusting comments. Their screw lengths are **M3×10** and **M3×8**, respectively; the corrected audit uses the top of the seated countersunk head as the length datum. It conservatively reports about **5.2 mm engagement** at 0.25 mm sampling resolution.
- One Nano-side lid boss uses a **2.7 mm radius**, retaining a **1.45 mm collar** around its M3 pilot. The other lid bosses retain 4 mm radius. That local collar is for a light prototype lid joint, not a high-load security claim.
- Print/CNC fit profiles are separate. CNC exports go to `cnc-design/cnc-profile/` by default so they cannot overwrite the print set.

## Print-fit defaults (all tunable after calibration)

| Interface | Print profile | CNC nominal profile |
|---|---:|---:|
| Cap body / tunnel | Ø8 / Ø8.35 | Ø8 / Ø8.10 |
| Cap flange / counterbore | Ø10 / Ø10.35 | Ø10 / Ø10.10 |
| Ø6 plunger / cap bore | Ø6 / Ø6.30 | Ø6 / Ø6.10 |
| Bushing OD / A1 seat | Ø14 / Ø14.30 | Ø14 / Ø14.00 |
| Bushing OD / lid opening | Ø14 / Ø14.50 | Ø14 / Ø14.10 |
| Head / bushing ID | Ø10 / Ø10.30 | Ø10 / Ø10.30 |
| TPU stud / shell hole | Ø4.5 / Ø4.2, intentional interference | same |

Clearances are **diametral**, not per side. CNC profile remains a nominal engineering comparison, not authorization to machine. Printed cap wall at the Ø6.3 bore is 0.85 mm; the prototypes are only for motion/fit testing. Do not force the actual plunger or bushing into a tight print, or drill the cap's Ø8.35 running tunnel with an Ø8 drill and assume it has the required fit.

**Coupons first:**
- `latch_fit_coupon`: notch at the lowest-diameter corner. Four columns, left to right. Near-notch row: 8.15/8.25/8.35/8.45; middle: 6.10/6.20/6.30/6.40; far row: 10.3/10.4/10.5/10.6. These are vertical bores, with the coupon flat on the bed.
- `horizontal_latch_coupon`: base down, X-axis through-bores. Low row: 8.15/8.25/8.35/8.45; high row: 10.15/10.25/10.35/10.45, ordered away from the notched Y end. This reproduces horizontal tunnel orientation. A good vertical fit does not establish horizontal roundness.

## Print scope and orientations

The print package intentionally omits **A3 spool housing, A4 spool cover and the metal hinge pin**. The spool remains a separate unfinished mechanism. The cover's corrected model is retained in the full CAD but is not on today's print list. Other purchased `ref_*` models and assembly STEP files are for inspection, not slicing.

| Part | Bed orientation | Starting support requirement |
|---|---|---|
| A1 top box | pocket UP, saddle DOWN | supports under saddle and carrier attachment geometry as slicer preview requires; keep removable support out of running bores if possible |
| A2 lid | exterior TOP face DOWN | underside recesses face UP; inspect screw-hole first layers |
| A5 insert | flange DOWN | none expected |
| electronics_cradle | assembled FLOOR faces DOWN | supports under elevated shelves/bridge; inspect 0.6 mm front stop and 0.7–0.8 mm rails with chosen nozzle |
| ref_tray | reader DECK DOWN | local support under screw ears; new ears make the old support-free claim obsolete |
| C1/C2 | seam faces DOWN | preview curved bores and side holes |
| closure_block | suitable flat face DOWN | saddle surface may need support; check contact face |
| hinge_block | pin axis vertical is a trial alternative | underside/locating surfaces require slicer review; no guaranteed support-free orientation |
| liner halves | tube axis vertical, brim | TPU studs remain short sideways overhangs; print a fit section before both full liners |
| proto_cable_head | nose DOWN, brim | inspect horizontal cord hole bridge |
| proto_cap | flange DOWN | inspect 6.3 mm blind-bore roof bridge and cross-hole |
| proto_bushing | on end | none expected |
| both latch coupons | base DOWN | do not change orientation of horizontal test bores |

The package includes copies in these suggested orientations, dropped to Z=0. Block orientations are trials that still require your slicer review. No G-code or printer-specific toolpaths have been released. PETG for rigid parts, TPU95A for liners is the starting material choice; temperatures, perimeters and supports will be tuned from your printer settings.

## Hardware

Keep the existing chassis-to-box and clamp-to-block M3×10 countersunk screws. Changes/additions:

| Joint | Hardware |
|---|---|
| A2 → A1 | 4× M3×10, 90° countersunk; assumed head Ø5.5 |
| A4 → A3, **deferred** | 4× M3×8, 90° countersunk |
| Carrier → A1 | 4× M2×5 pan, head envelope Ø4×1.6; Ø2.4 carrier clearance, Ø1.6 A1 pilot; 3 mm nominal engagement |
| Tray → A1 | 2× M3×6 pan, head envelope Ø5.5×2.4; Ø3.4 clearance, Ø2.5 A1 pilot; 4 mm nominal engagement for a light tray |
| Consumer closure | M3×6 **low-head cap** plus Ø7×0.5 washer, on flat bore floor; **not a countersunk screw with a washer** |
| Retention | 11× 2.5×0.7 ties with heads no larger than the modeled 4×4×3 envelope; 150 mm or longer |

In PETG, these pilots are provisional self-tap pilots. Test a spare hole, drive gently and verify retention; the audit checks geometric engagement, not pullout strength. Do not insert heat-set inserts in these holes. Verify your head dimensions and screw lengths before final assembly.

## Electronics mounting sequence

1. Clean A1, carrier and tray. Check tie slots, screw wells, board seats and running bores. Dry-fit all purchased parts before fastening.
2. Thread loose battery/Nano/charger ties into A1's floor grooves. Feed coil, driver and boost ties around their carrier seats, and reader ties through the tray slots. Put reader lock heads **under the deck**, not above the antenna board; other heads go in the modeled free zones.
3. Drop the empty carrier into A1 and attach with four M2×5 screws. Two screw heads sit on the coil-side floor rail; the two rear screws are reached through open wells in the boost-support rail. Install these before the coil/boards.
4. Battery sits directly on A1 at x19.5–69.5, y−7–27, z38. Set its straps snug enough to locate it, **without squeezing the pouch**. Do not place sharp tie heads against the cell. The pouch's actual thickness/protection board/pigtail must match its envelope.
5. Place the tray above the cell and drive two M3×6 screws at (16.2,8) and (16.2,22). Its screw heads and tool paths stay clear of the cell. Reader sits on the deck at z57.5, component side up, wires down through the header slot. Fit reader straps with their heads under the deck, clear of the battery straps. Actual PCB components may need thin foam where a tie contacts them; do not bend the PCB or cover header pads.
6. TP4056 sits on the floor at x117–146, y−5.5–11.8, USB toward +X, guided by the carrier rails. Fit its strap at x128, clear of its −X solder pads and USB receptacle. The battery harness passes beneath the carrier's raised cross-bridge.
7. Nano sits on the floor at x100.5–145.5, y17.5–35.5, USB toward −X. Its central lengthwise strap avoids the modeled side pin/wire zones. **Cut/remove this replaceable strap and lift the lid to reflash over USB**; put a new strap on afterward. Its front strap obstructs the USB plug when retained.
8. Driver card sits at x102.5–142.5, y5.6–16.3, base z45.15. Fit its two straps at x118 and130. Use the **40×10.7×13.6 envelope** from the current CAD; old 42 mm card instructions are obsolete for this packaging.
9. MT3608 sits at x110–146, y18.5–35.5, base z51.7 on the raised shelf, with wires at its X ends. Straps at x122 and135 avoid these end-pad zones. The shelf is supported outside the Nano footprint, with space beneath it for Nano wiring.
10. Assemble the latch cap/front spring and seat the coil on the two real carrier pillars: x110.8–139.4, y−12.75–4.75, z45.65–58.35. The **lengthwise coil tie at y−10.5** stays clear of the plunger/front spring. Stops locate its X ends; verify that tightening the tie does not shift the 2.6 mm stroke setting. Solenoid tab holes have intentionally not been guessed.
11. Dry-fit the lid-mounted buttons/LEDs/buzzer and revised bushing/window. Test scan/unlock on the bench before closing the lid. Check the real nut, wire, tie-head and solder-joint envelopes. Use the repo's current Nano/RC522 layout; an ESP32 or another board needs a different carrier.
12. Test printed head insertion/release repeatedly by hand, then powered, without security loads. Real spring solid height/rate, coil force, wire bends, component heights, screw pullout and printer fits remain physical checks. Nothing here completes the donor spool or its spring anchorage.

## Reproduce

```bash
python cad/cnc_casing_cq.py --profile print --audit
python cad/cnc_casing_cq.py --profile print
python cad/cnc_casing_cq.py --profile cnc --audit
python cad/cnc_casing_cq.py --mounts
python review/rev3f/validate_release.py
```

The full audit checks the complete static assembly, installation hinge sweep at 0/0.5/1…60° including the left TPU liner and every fixed component, frame entry, latch states, wiring envelopes, screw engagement, actual countersink angles, carrier/tray mounting-axis clearance, real support beneath each component and single-solid validity. Interference threshold remains 0.05 mm³. Sampled motion is not a continuous-motion proof. Physical locking strength, spring force and print fidelity are not claimed.

Old rev3e shop drawings and inspection renders are superseded for changed parts. Do not machine from those drawings or from this print-profile release.

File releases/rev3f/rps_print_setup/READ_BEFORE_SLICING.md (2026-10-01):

# VELOX rev3f with supplied RPS v9 presets

Use the 16 labeled STEP files in this package. Units are mm; suggested orientations are already applied. Print the two latch fit coupons first. Spool parts and the metal hinge pin remain excluded.

## Filament assignment

- All 14 rigid parts and coupons: **RPS Settings - PETG**, inheriting **Creality Generic PETG**.
- Both liners: **RPS Settings - TPU**, inheriting **Creality Generic TPU**. The preset does not specify Shore hardness; verify the intended TPU95A material before accepting the press fit.
- Supplied ASA/PLA presets are preserved but not assigned to these parts.

## What the supplied archive establishes

The profiles list Creality K1, K1 Max, K1C and K2 Plus with 0.4 mm nozzles. This does not establish which machine is being used. PETG and TPU contain no explicit nozzle/bed temperature, flow ratio, retraction, volumetric speed or shrinkage overrides: these must resolve from the named installed base presets. JSON version fields are profile metadata, not confirmation of the installed slicer version.

Import these filament presets into the shop's compatible slicer and confirm each base resolves without warnings. Select the actual machine and process profile. Keep PETG and TPU on separate plates/jobs. Refer to PRINT_BUILD_REV3F.md for part-specific orientation and support requirements. Review support removability, the 0.6 mm stop and 0.7–0.8 mm carrier rails, bore bridges and bed fit in the actual preview. Do not add global hole/XY compensation before printing and measuring the orientation-specific coupons: allowances are already in the CAD.

This package assigns supplied material presets to parts; it does not contain sliced projects or G-code. Exact printer model and slicer/process profile remain needed. No geometry changes were made from these filament-only profiles.

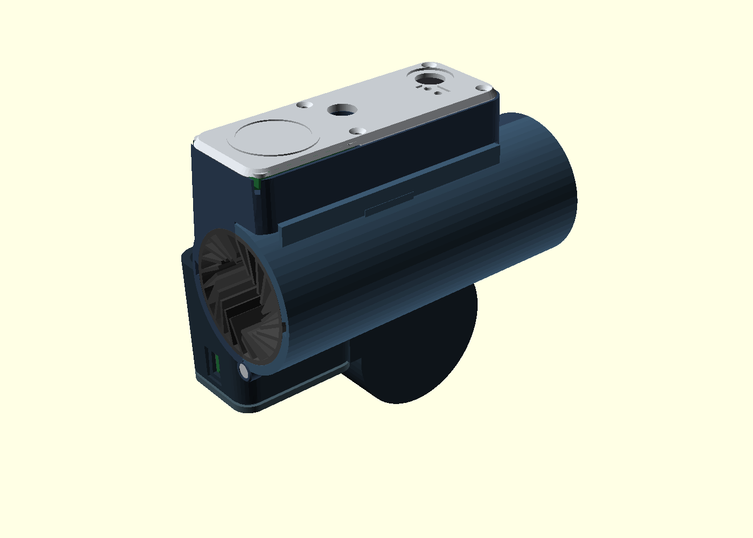
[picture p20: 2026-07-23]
renders/assembly_closed_v082.png

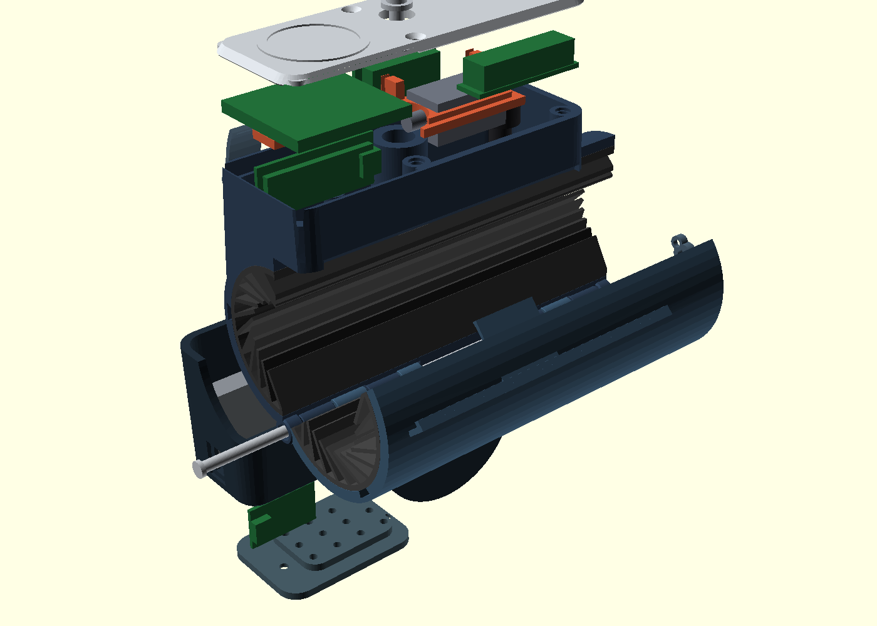
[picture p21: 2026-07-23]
renders/assembly_exploded_v082.png

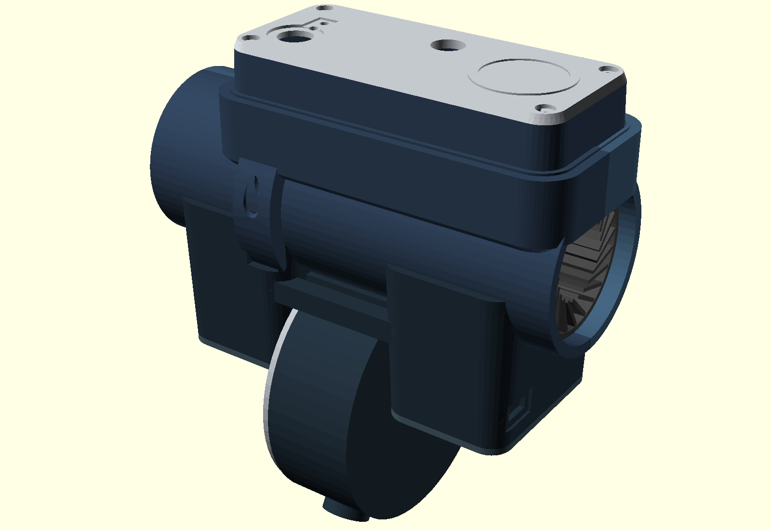
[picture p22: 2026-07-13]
cad/renders/assembly_hero.png

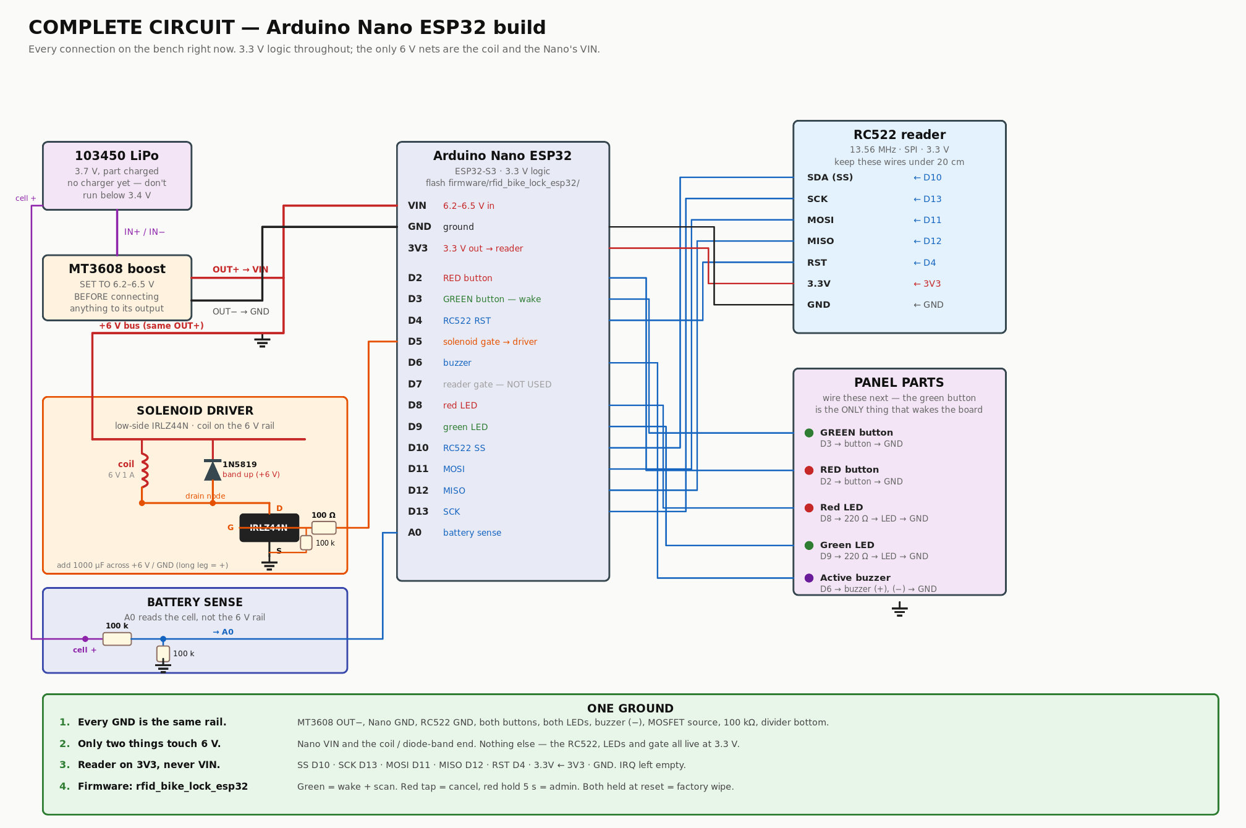
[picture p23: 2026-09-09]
renders/electrical/bench_wiring_esp32.png

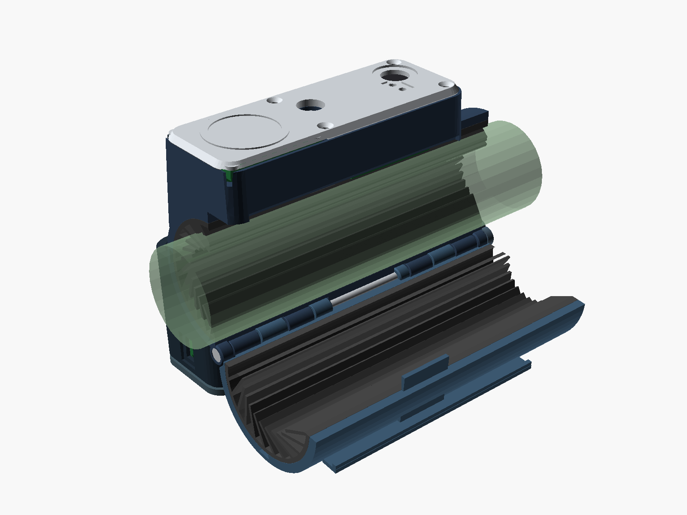
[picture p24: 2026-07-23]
cad/renders/assembly_open.png

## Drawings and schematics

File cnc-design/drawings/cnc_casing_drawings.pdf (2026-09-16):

A

### TOP

150.0

31.8

### BACK

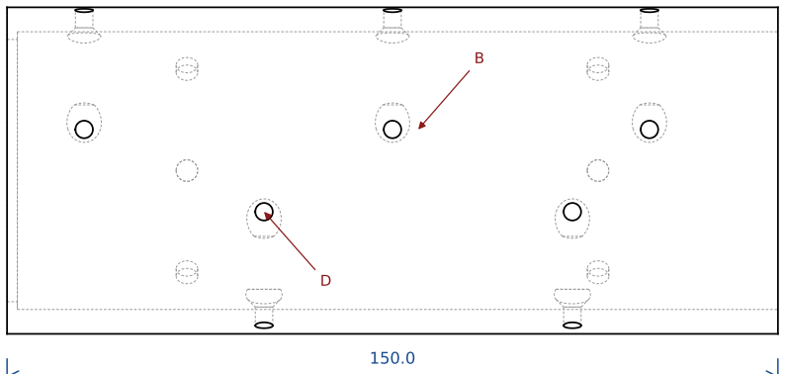
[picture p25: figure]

63.5

C

### RIGHT

31.7

63.5

### ISO (not to scale)

### NOTES

- Pair of halves from one saw-cut tube, split on the y=0 plane,

line-bored together to Ø54.0

- All screw countersinks (90 deg, O6.3 at the surface) are cut

from the BORE side; heads sit 0.4 sub-flush under the liner

- Rear liner lip: x 148..150, inward to R25.5
- Top rows feed A1 (x 25/70/130); bottom rows feed A3 (x

40/100). Do not mix them up

### HOLE / FEATURE SCHEDULE

A: 3x Ø3.4 THRU vertical at y=+6 (top crown row), 90° CSK Ø6.3

from the bore @ x 25, 75, 135

B: 3x Ø3.4 THRU horizontal (+y) at z=+8 (top skirt row), 90°

CSK Ø6.3 from the bore @ x 25, 75, 135

C: 2x Ø3.4 THRU vertical at y=+10 (bottom crown row), 90° CSK

Ø6.3 from the bore @ x 40, 100

D: 2x Ø3.4 THRU horizontal (+y) at z=-8 (bottom skirt row),

90° CSK Ø6.3 from the bore @ x 40, 100

### GENERAL

Units mm. Datum: tube axis = X, seam plane y=0, Z up. Break sharp edges 0.3.

Stage 1 (PETG): print on the face noted, pilots self-tap M3. Metal: tap M3x0.5.

Internal corners R4 unless the model shows R6. Tolerance ±0.1 on fits, ±0.3 elsewhere.

## RFID BIKE LOCK - CNC CASING

cad/cnc_casing_cq.py rev 3e

## C1 - chassis half (carries the boxes)

file: cnc-design/step/C1_chassis_half.step

MATERIAL

6061-T6 tube 2.5" OD x 3/16" wall, or PETG (stage 1)

QTY

SCALE (ortho views)

0.73 : 1

BOUNDING BOX x / y / z

150.0 / 31.8 / 63.5 (x -0.0..150.0, y -0.0..31.8, z -31.8..31.8)

DATE

2026-09-16

SHEET

3rd angle

A3 landscape

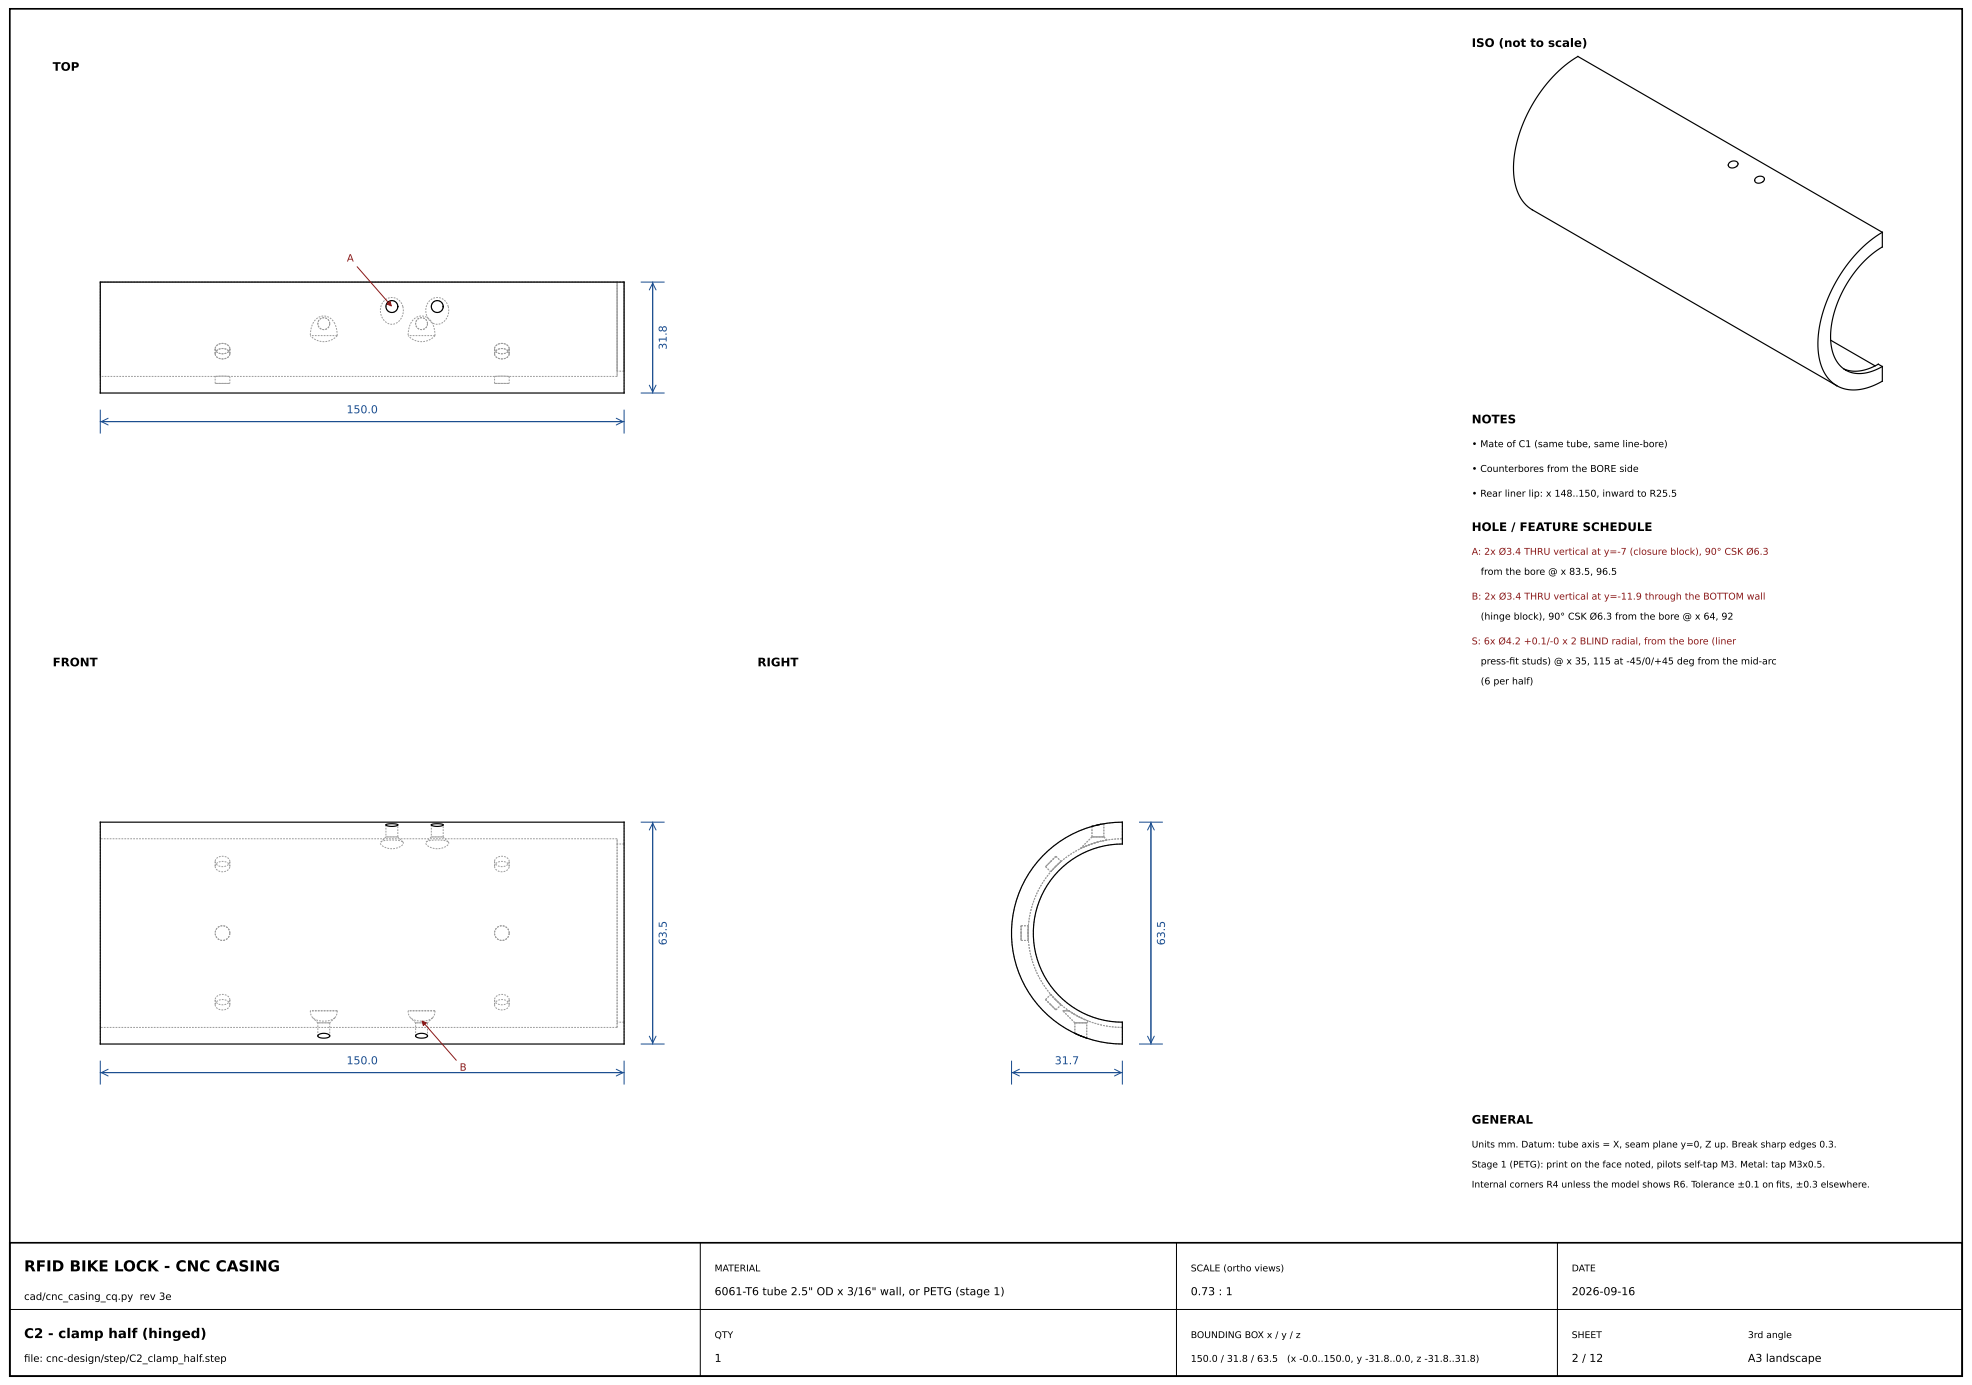
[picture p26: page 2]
FRONT; RIGHT; NOTES; (6 per half); GENERAL; MATERIAL; DATE

• Mate of C1 (same tube, same line-bore)

• Counterbores from the BORE side

• Rear liner lip: x 148..150, inward to R25.5

HOLE / FEATURE SCHEDULE

A: 2x Ø3.4 THRU vertical at y=-7 (closure block), 90° CSK Ø6.3

from the bore @ x 83.5, 96.5

B: 2x Ø3.4 THRU vertical at y=-11.9 through the BOTTOM wall

(hinge block), 90° CSK Ø6.3 from the bore @ x 64, 92

S: 6x Ø4.2 +0.1/-0 x 2 BLIND radial, from the bore (liner
press-fit studs) @ x 35, 115 at -45/0/+45 deg from the mid-arc

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

Stage 1 (PETG): print on the face noted, pilots self-tap M3. Metal: tap M3x0.5.
Internal corners R4 unless the model shows R6. Tolerance ±0.1 on fits, ±0.3 elsewhere.

RFID BIKE LOCK - CNC CASING

SCALE (ortho views)

6061-T6 tube 2.5" OD x 3/16" wall, or PETG (stage 1)

C2 - clamp half (hinged)

file: cnc-design/step/C2_clamp_half.step

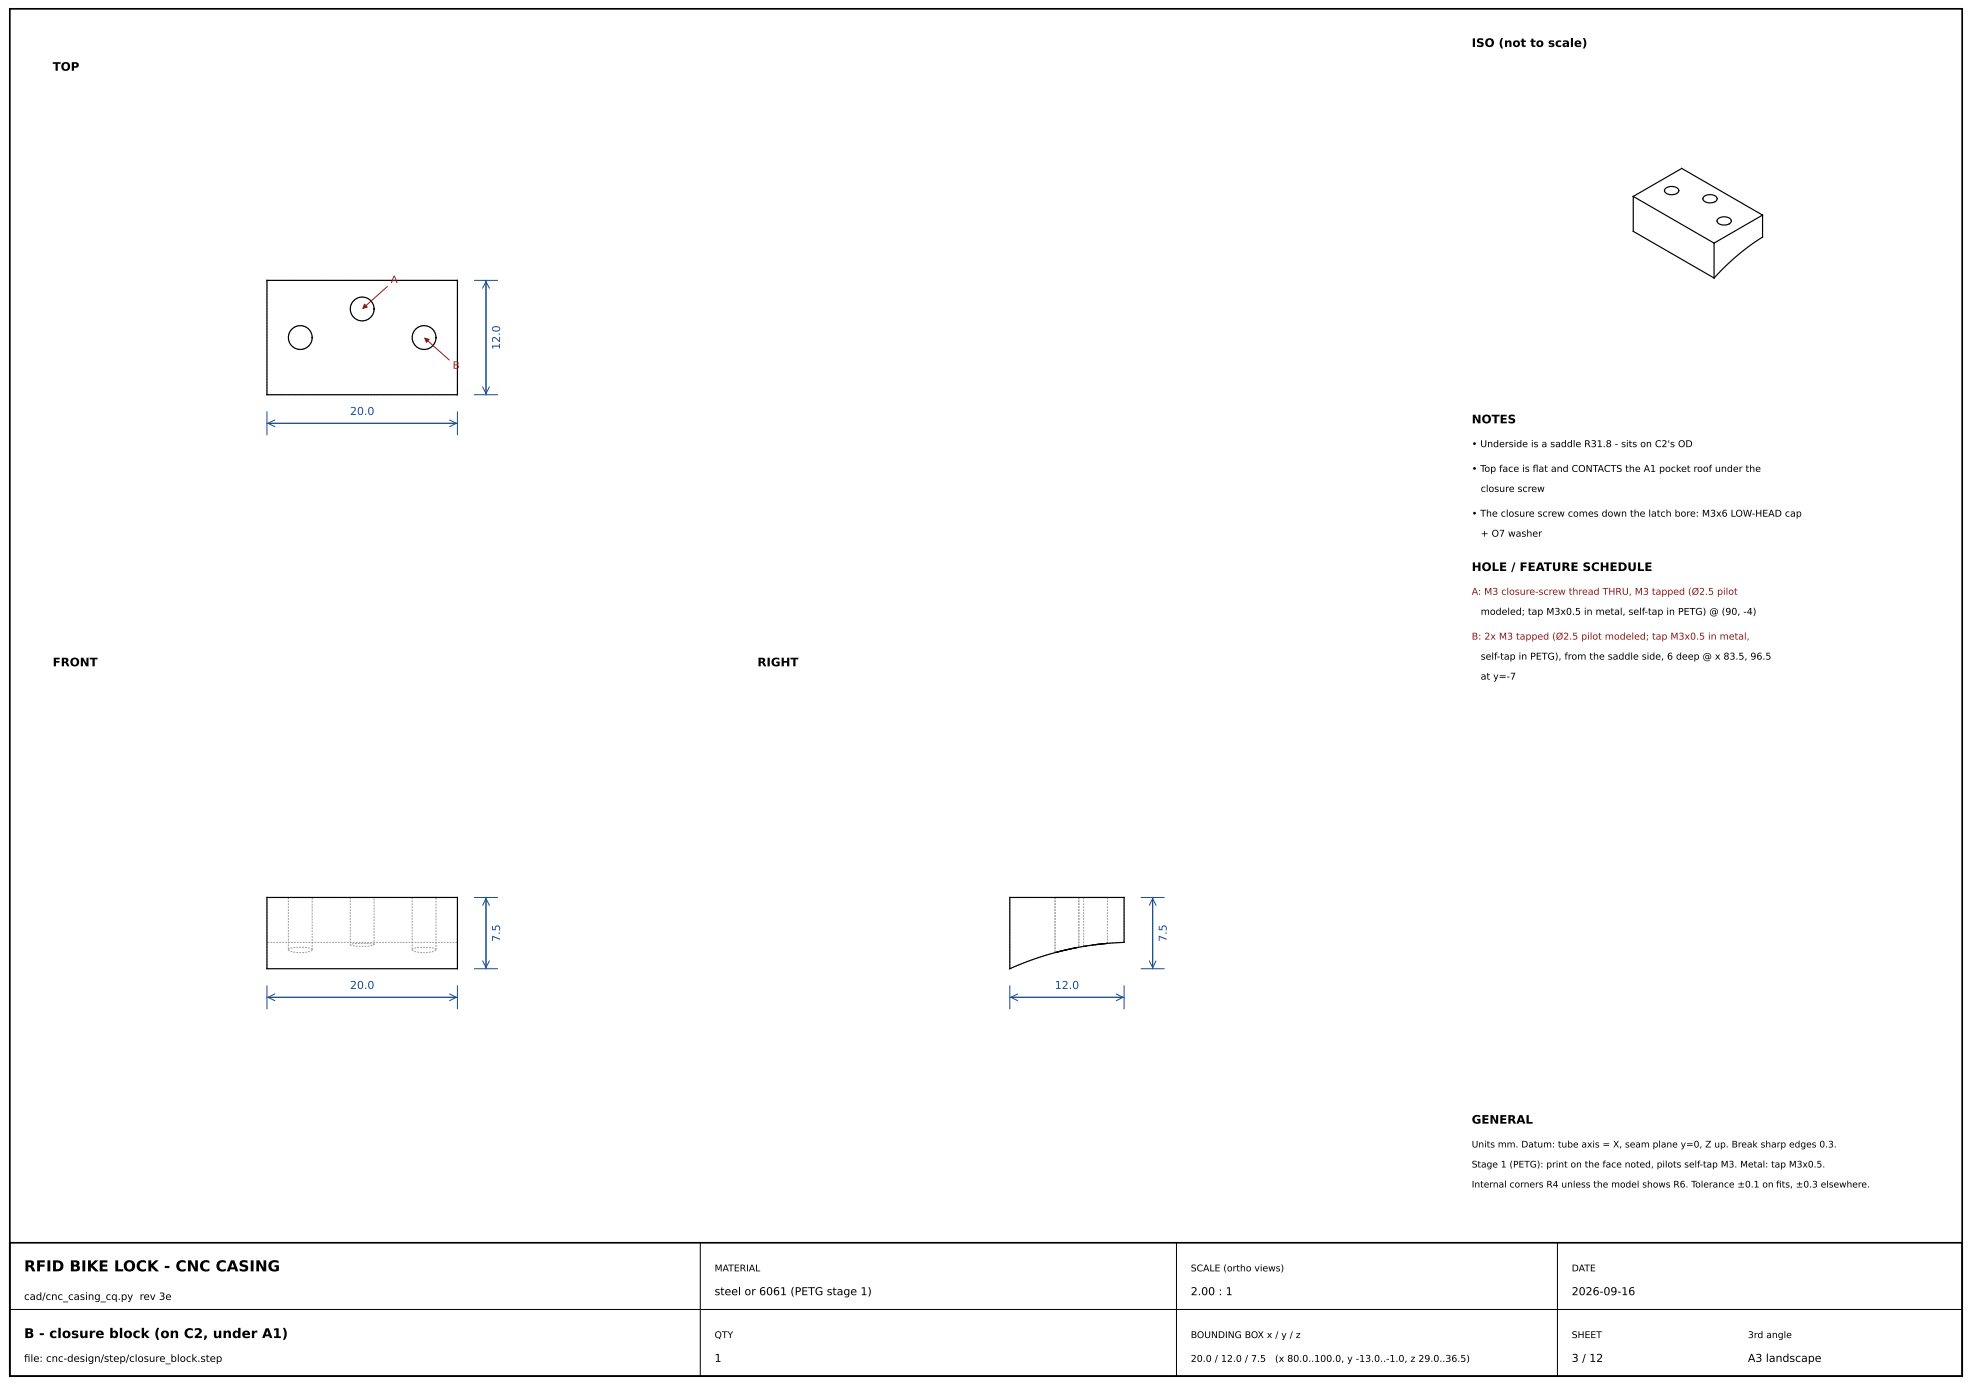
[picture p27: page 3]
FRONT; RIGHT; NOTES; closure screw; + O7 washer; GENERAL; MATERIAL; DATE

• Underside is a saddle R31.8 - sits on C2's OD

• Top face is flat and CONTACTS the A1 pocket roof under the

• The closure screw comes down the latch bore: M3x6 LOW-HEAD cap

HOLE / FEATURE SCHEDULE

A: M3 closure-screw thread THRU, M3 tapped (Ø2.5 pilot

modeled; tap M3x0.5 in metal, self-tap in PETG) @ (90, -4)

B: 2x M3 tapped (Ø2.5 pilot modeled; tap M3x0.5 in metal,

self-tap in PETG), from the saddle side, 6 deep @ x 83.5, 96.5

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

RFID BIKE LOCK - CNC CASING

SCALE (ortho views)

steel or 6061 (PETG stage 1)

B - closure block (on C2, under A1)

file: cnc-design/step/closure_block.step

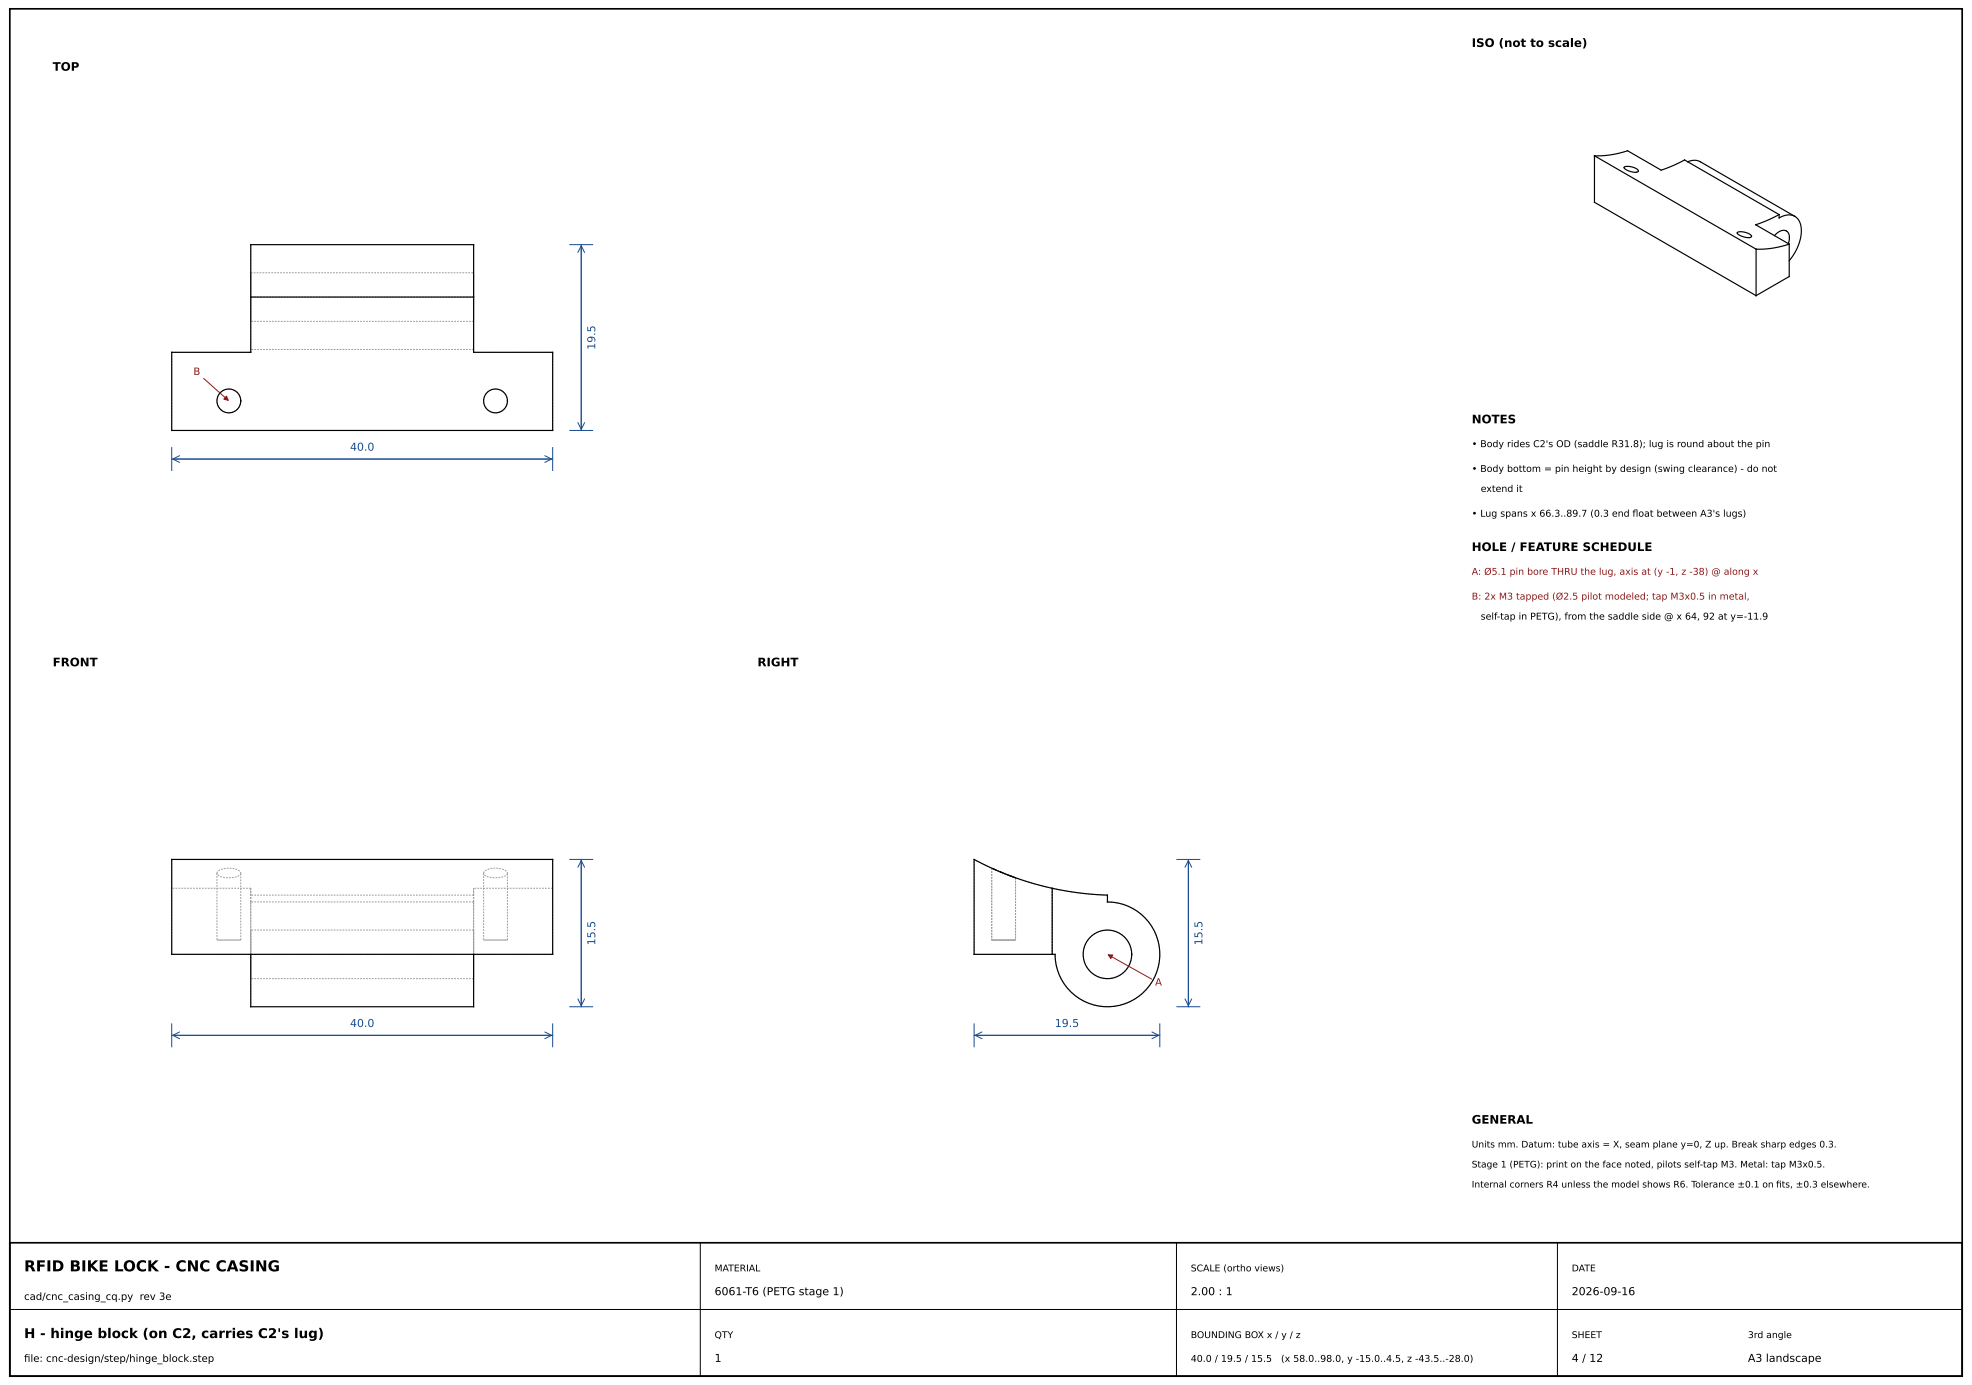
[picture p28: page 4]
FRONT; RIGHT; NOTES; extend it; GENERAL; MATERIAL; 6061-T6 (PETG stage 1); DATE

• Body rides C2's OD (saddle R31.8); lug is round about the pin

• Body bottom = pin height by design (swing clearance) - do not

• Lug spans x 66.3..89.7 (0.3 end float between A3's lugs)

HOLE / FEATURE SCHEDULE

A: Ø5.1 pin bore THRU the lug, axis at (y -1, z -38) @ along x

B: 2x M3 tapped (Ø2.5 pilot modeled; tap M3x0.5 in metal,

self-tap in PETG), from the saddle side @ x 64, 92 at y=-11.9

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

RFID BIKE LOCK - CNC CASING

SCALE (ortho views)

H - hinge block (on C2, carries C2's lug)

file: cnc-design/step/hinge_block.step

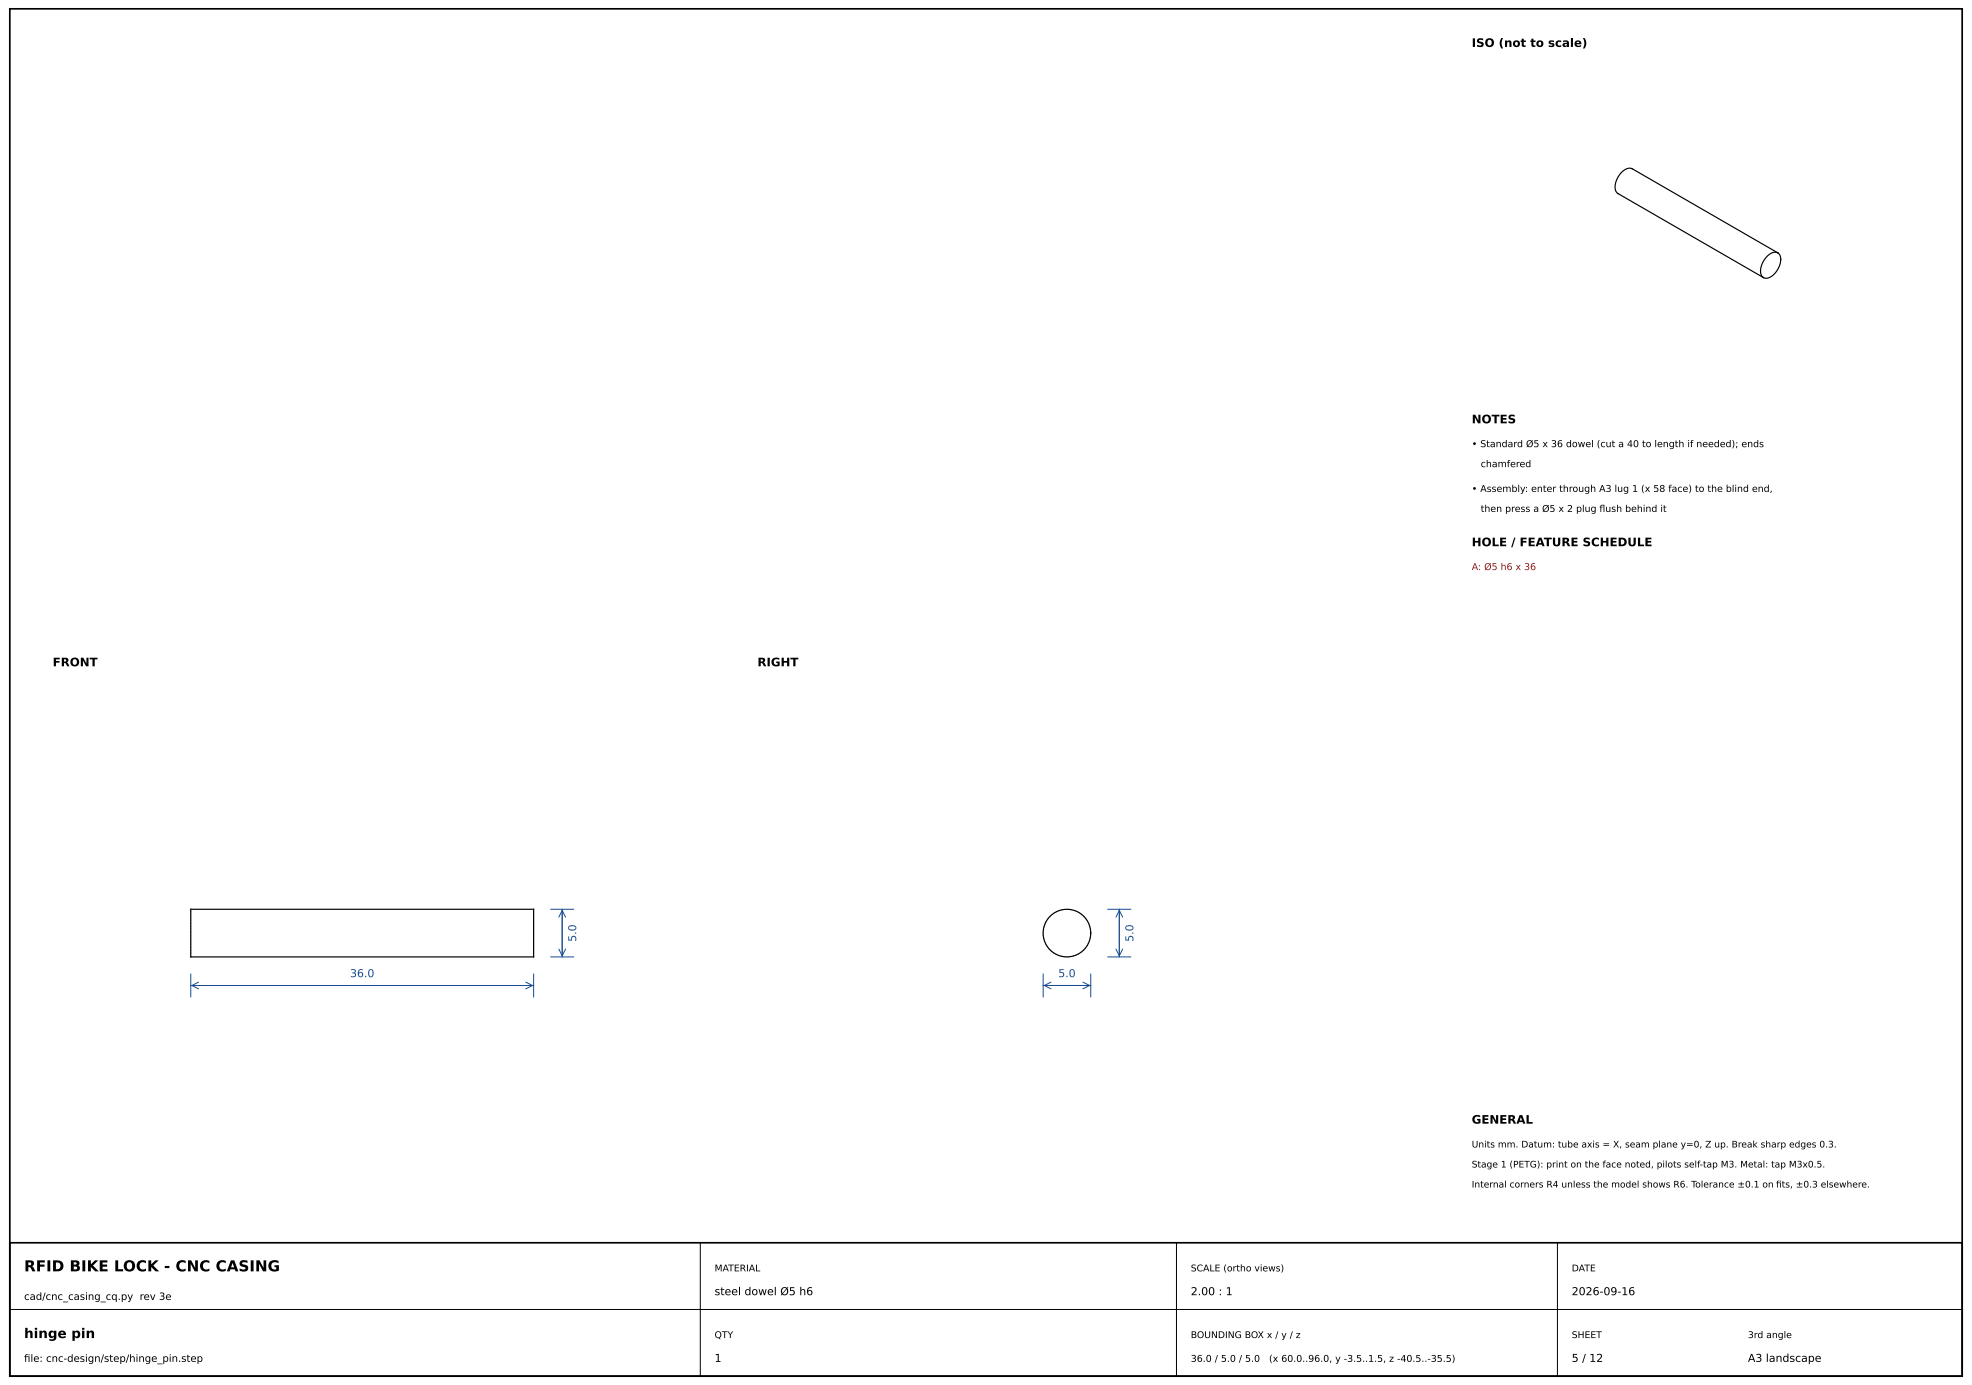
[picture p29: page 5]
FRONT; RIGHT; NOTES; chamfered; GENERAL; hinge pin; MATERIAL; steel dowel Ø5 h6; DATE
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

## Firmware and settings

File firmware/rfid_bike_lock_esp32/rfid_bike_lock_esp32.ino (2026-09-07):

/*
 * RFID Bike Lock — v1 firmware, Arduino Nano ESP32 build
 * Target: Arduino Nano ESP32 (ESP32-S3), 3.3 V logic
 * Reader: RC522 over SPI — wired DIRECTLY, no level shifters (both are 3.3 V parts)
 *
 * Same behaviour and same key set as the AVR builds; the differences are all
 * platform plumbing:
 *   - Sleep is ESP32 DEEP SLEEP, which resets the chip on wake. So the whole
 *     scan window lives in setup() and the sketch deep-sleeps at the end of it;
 *     loop() never runs. Waking is ext0 on the GREEN button (LOW level).
 *   - Tag storage is Preferences (NVS), not the AVR EEPROM library. Records are
 *     kept as fixed 8-byte blobs so the layout still mirrors DESIGN.md §5.
 *   - The ADC is 12-bit against 3.3 V, so the battery maths differ from AVR's
 *     10-bit / 5 V. Divider is unchanged (100k:100k).
 *
 * Power notes (WIRING.md):
 *   - The 6.2–6.5 V rail feeds VIN; the board's own regulator makes 3.3 V.
 *   - The RC522 runs from the board's 3V3 pin.
 *   - The solenoid runs from the 6 V rail through the IRLZ44N; a 3.3 V gate
 *     drives it adequately for a ~1 A coil.
 */

#include <SPI.h>
#include <MFRC522.h>
#include <Preferences.h>
#include <esp_sleep.h>

// ---------- Debug ----------
// Comment out for the battery-powered unit: USB CDC keeps the radio-side awake
// and costs current.
#define DEBUG

#ifdef DEBUG
  #define DBG(x)   Serial.print(x)
  #define DBGLN(x) Serial.println(x)
#else
  #define DBG(x)
  #define DBGLN(x)
#endif

// ---------- Pins (Nano ESP32 silkscreen names) ----------
const uint8_t PIN_WAKE_BTN   = D3;   // GREEN button to GND — the ONLY deep-sleep wake source
const uint8_t PIN_ADMIN_BTN  = D2;   // RED button to GND — tap = cancel, hold = admin
const uint8_t PIN_RC522_RST  = D4;
const uint8_t PIN_SOLENOID   = D5;   // IRLZ44N gate (HIGH = energized)
const uint8_t PIN_BUZZER     = D6;   // ACTIVE buzzer (+); HIGH = sound
const uint8_t PIN_READER_PWR = D7;   // P-FET gate, LOW = reader powered (optional; see NOTE)
const uint8_t PIN_LED_RED    = D8;
const uint8_t PIN_LED_GREEN  = D9;
const uint8_t PIN_RC522_SS   = D10;
// The ESP32 core does not always map the default SPI bus onto the Nano's D11/D12/D13
// silkscreen pins, so SPI.begin() is called with them explicitly below.
const uint8_t PIN_RC522_SCK  = D13;
const uint8_t PIN_RC522_MISO = D12;
const uint8_t PIN_RC522_MOSI = D11;
const uint8_t PIN_VBAT_SENSE = A0;   // battery / 2 via 100k:100k

// NOTE on PIN_READER_PWR: gating a 3.3 V rail with the IRF4905 is marginal (its
// gate threshold is -2..-4 V, and 3.3 V logic can only reach -3.3 V). Use the
// AO3401 from the SOT-23 kit, which is logic-level, or leave the reader
// permanently powered until the sleep-current measurement says it matters.
#define READER_POWER_GATED 0         // set to 1 once a logic-level P-FET is fitted

// ---------- Development switch ----------
// Deep sleep kills the USB peripheral, so the IDE can't reset the board into its
// bootloader and every upload fails with "No DFU capable USB device available"
// until you double-tap RESET by hand. With DEV_NO_SLEEP the board idles awake
// between scan windows instead, USB stays alive, and uploads just work.
// SET THIS TO 0 FOR THE BATTERY BUILD — idling awake costs ~10x the current.
#define DEV_NO_SLEEP 1

// ---------- Timing ----------
const uint32_t SCAN_WINDOW_MS      = 10000;
const uint32_t SOLENOID_PULSE_MS   = 300;   // try 150 once you see how hard it pulls
const uint32_t ADMIN_HOLD_MS       = 5000;
const uint32_t ADMIN_TIMEOUT_MS    = 15000;
const uint32_t SAME_UID_LOCKOUT_MS = 2000;

// ---------- Battery ----------
const float    VBAT_LOW      = 3.50;  // low-battery warning threshold (V)
const float    VBAT_DIVIDER  = 2.0;   // 100k:100k
const float    VREF          = 3.3;   // ESP32 ADC full scale with 11 dB attenuation
const int      ADC_MAX       = 4095;  // 12-bit

// ---------- Tag store (Preferences / NVS) ----------
// Keys: "magic" (u8), "count" (u8), "master" (8-byte blob), "t0".."t9" (8-byte blobs).
// Blob layout matches the AVR builds: [len][uid bytes, zero-padded to 7].
const uint8_t  NVS_MAGIC   = 0x42;
const uint8_t  UID_REC_SIZE = 8;
const uint8_t  MAX_TAGS     = 10;
Preferences store;

MFRC522 rfid(PIN_RC522_SS, PIN_RC522_RST);

// ---------- LED helpers ----------
void blink(uint8_t pin, uint8_t times, uint16_t onMs = 120, uint16_t offMs = 120) {
  for (uint8_t i = 0; i < times; i++) {
    digitalWrite(pin, HIGH); delay(onMs);
    digitalWrite(pin, LOW);  delay(offMs);
  }
}

void blinkAlternating(uint8_t cycles) {
  for (uint8_t i = 0; i < cycles; i++) {
    digitalWrite(PIN_LED_RED, HIGH);   delay(100); digitalWrite(PIN_LED_RED, LOW);
    digitalWrite(PIN_LED_GREEN, HIGH); delay(100); digitalWrite(PIN_LED_GREEN, LOW);
  }
}

// ---------- Buzzer (ACTIVE type: on/off only) ----------
void beep(uint16_t onMs, uint8_t n = 1, uint16_t gapMs = 80) {
  for (uint8_t i = 0; i < n; i++) {
    digitalWrite(PIN_BUZZER, HIGH); delay(onMs);
    digitalWrite(PIN_BUZZER, LOW);
    if (i + 1 < n) delay(gapMs);
  }
}
#define BEEP_WAKE()    beep(40)
#define BEEP_OK()      beep(60, 2, 60)
#define BEEP_DENIED()  beep(400)
#define BEEP_ADMIN()   beep(120, 3, 80)
#define BEEP_LOWBAT()  beep(700)

// ---------- Battery ----------
float readBatteryVolts() {
  analogRead(PIN_VBAT_SENSE);                  // throwaway read settles the mux
  int raw = analogRead(PIN_VBAT_SENSE);
  return raw * (VREF / (float)ADC_MAX) * VBAT_DIVIDER;
}

// ---------- Tag records ----------
static void recKey(char *buf, int slot) { snprintf(buf, 8, "t%d", slot); }

void recWrite(const char *key, const uint8_t *uid, uint8_t len) {
  uint8_t rec[UID_REC_SIZE] = {0};
  rec[0] = len;
  for (uint8_t i = 0; i < 7 && i < len; i++) rec[1 + i] = uid[i];
  store.putBytes(key, rec, UID_REC_SIZE);
}

bool recMatch(const char *key, const uint8_t *uid, uint8_t len) {
  uint8_t rec[UID_REC_SIZE] = {0};
  if (store.getBytes(key, rec, UID_REC_SIZE) != UID_REC_SIZE) return false;
  if (rec[0] != len) return false;
  for (uint8_t i = 0; i < len; i++) if (rec[1 + i] != uid[i]) return false;
  return true;
}

bool isMaster(const uint8_t *uid, uint8_t len) { return recMatch("master", uid, len); }

int findTag(const uint8_t *uid, uint8_t len) {
  uint8_t count = store.getUChar("count", 0);
  if (count > MAX_TAGS) count = 0;                    // corrupt guard
  char key[8];
  for (uint8_t s = 0; s < count; s++) {
    recKey(key, s);
    if (recMatch(key, uid, len)) return s;
  }
  return -1;
}

bool isAuthorized(const uint8_t *uid, uint8_t len) {
  return isMaster(uid, len) || findTag(uid, len) >= 0;
}

bool addTag(const uint8_t *uid, uint8_t len) {
  uint8_t count = store.getUChar("count", 0);
  if (count >= MAX_TAGS) return false;
  char key[8]; recKey(key, count);
  recWrite(key, uid, len);
  store.putUChar("count", count + 1);
  return true;
}

void removeTag(int slot) {                            // compact: move the last record down
  uint8_t count = store.getUChar("count", 0);
  if (count == 0 || slot < 0 || slot >= count) return;
  char dst[8], src[8];
  recKey(dst, slot); recKey(src, count - 1);
  if (slot != count - 1) {
    uint8_t rec[UID_REC_SIZE] = {0};
    store.getBytes(src, rec, UID_REC_SIZE);
    store.putBytes(dst, rec, UID_REC_SIZE);
  }
  store.putUChar("count", count - 1);
}

// ---------- Reader ----------
bool readerOn() {
#if READER_POWER_GATED
  digitalWrite(PIN_READER_PWR, LOW);
  delay(30);
#endif
  SPI.begin(PIN_RC522_SCK, PIN_RC522_MISO, PIN_RC522_MOSI, PIN_RC522_SS);
  rfid.PCD_Init();
  delay(10);
  byte v = rfid.PCD_ReadRegister(MFRC522::VersionReg);
#ifdef DEBUG
  DBG(F("[reader] VersionReg = 0x"));
  if (v < 0x10) DBG("0");
  Serial.println(v, HEX);
  DBGLN(F("        0x91/0x92 = genuine · 0x88/0x12 = clone, usually fine"));
  DBGLN(F("        0x00/0xFF = NOT COMMUNICATING (check SS, SCK, MOSI, MISO, RST, 3V3)"));
#endif
  if (v == 0x00 || v == 0xFF) return false;           // nothing answering on the bus
  rfid.PCD_AntennaOn();
  rfid.PCD_SetAntennaGain(MFRC522::RxGain_max);       // max gain: best chance through a lid
  return true;
}

void readerOff() {
  rfid.PCD_AntennaOff();
  rfid.PCD_SoftPowerDown();
  SPI.end();
#if READER_POWER_GATED
  digitalWrite(PIN_READER_PWR, HIGH);
#endif
}

// Poll for a tag with a bounded wait. Returns true and fills uid/len.
bool readTag(uint8_t *uid, uint8_t *len, uint16_t timeoutMs) {
  uint32_t t0 = millis();
  while (millis() - t0 < timeoutMs) {
#ifdef DEBUG
    static uint32_t lastPoll = 0;
    if (rfid.PICC_IsNewCardPresent() && millis() - lastPoll > 500) {
      lastPoll = millis();
      DBGLN(F("[reader] card detected, reading serial..."));
    }
#endif
    if (rfid.PICC_IsNewCardPresent() && rfid.PICC_ReadCardSerial()) {
      *len = rfid.uid.size;
      for (uint8_t i = 0; i < *len && i < 7; i++) uid[i] = rfid.uid.uidByte[i];
      rfid.PICC_HaltA();
      return true;
    }
    delay(20);
  }
  return false;
}

// ---------- Solenoid ----------
void fireUnlock() {
  digitalWrite(PIN_SOLENOID, HIGH);
  delay(SOLENOID_PULSE_MS);
  digitalWrite(PIN_SOLENOID, LOW);
}

// ---------- Sleep ----------
// Shared teardown: everything off, reader parked, NVS closed.
void powerDown() {
  readerOff();
  digitalWrite(PIN_LED_RED, LOW);
  digitalWrite(PIN_LED_GREEN, LOW);
  digitalWrite(PIN_SOLENOID, LOW);
  digitalWrite(PIN_BUZZER, LOW);
  store.end();
#ifdef DEBUG
  Serial.flush();
#endif
}

void goToSleep() {
  powerDown();
  DBGLN(F("[sleep] deep sleep — press GREEN to wake"));
  // ext0: wake when the GREEN button pulls its pin LOW.
  esp_sleep_enable_ext0_wakeup((gpio_num_t)digitalPinToGPIONumber(PIN_WAKE_BTN), 0);
  esp_deep_sleep_start();                              // ---- never returns ----
}

// Development idle: same teardown, but stay awake so USB survives and uploads work.
void idleUntilWake() {
  powerDown();
  DBGLN(F("[idle] awake for uploads (DEV_NO_SLEEP) — press GREEN for another window"));
  while (digitalRead(PIN_WAKE_BTN) == HIGH) delay(20);
  while (digitalRead(PIN_WAKE_BTN) == LOW)  delay(20);   // wait for release
  delay(30);                                            // debounce
  store.begin("biketags", false);
}

// ---------- Admin mode ----------
void runAdminMode() {
  DBGLN(F("[admin] entered — tap master to confirm"));
  blinkAlternating(6);
  BEEP_ADMIN();

  uint8_t uid[7]; uint8_t len;
  bool masterOk = false;
  uint32_t t0 = millis();
  while (millis() - t0 < ADMIN_TIMEOUT_MS) {
    if (readTag(uid, &len, 400) && isMaster(uid, len)) { masterOk = true; break; }
  }
  if (!masterOk) { blink(PIN_LED_RED, 2); BEEP_DENIED(); return; }

  DBGLN(F("[admin] confirmed — tap a tag to add or remove"));
  blink(PIN_LED_GREEN, 1, 400, 0);
  BEEP_ADMIN();

  t0 = millis();
  while (millis() - t0 < ADMIN_TIMEOUT_MS) {
    if (!readTag(uid, &len, 400)) continue;
    t0 = millis();

    if (isMaster(uid, len)) { blink(PIN_LED_RED, 1); continue; }   // master not removable

    int slot = findTag(uid, len);
    if (slot >= 0) {
      removeTag(slot);
      DBGLN(F("[admin] removed"));
      blink(PIN_LED_RED, 3);
      beep(300);
    } else if (addTag(uid, len)) {
      DBGLN(F("[admin] added"));
      blink(PIN_LED_GREEN, 3);
      BEEP_OK();
    } else {
      DBGLN(F("[admin] full"));
      blink(PIN_LED_RED, 5, 60, 60);
    }
  }
  DBGLN(F("[admin] exit"));
  blinkAlternating(3);
  BEEP_ADMIN();
}

// ---------- First-boot master enrollment ----------
void enrollMaster() {
  DBGLN(F("[enroll] FIRST BOOT — present a fob to make it the MASTER key"));
  DBGLN(F("[enroll] (red/green alternating until one is read)"));
  uint8_t uid[7]; uint8_t len;
  while (true) {
    blinkAlternating(2);
    if (readTag(uid, &len, 400)) break;
  }
  recWrite("master", uid, len);
  store.putUChar("count", 0);
  store.putUChar("magic", NVS_MAGIC);
  DBGLN(F("[enroll] master stored"));
  blink(PIN_LED_GREEN, 5);
  BEEP_OK();
}

// ---------- Scan window ----------
void runScanWindow() {
  float v = readBatteryVolts();
  DBG(F("[wake] vbat=")); DBGLN(v);
  if (v < VBAT_LOW) { blink(PIN_LED_RED, 3); BEEP_LOWBAT(); }

  if (!readerOn()) {
    DBGLN(F("[err] RC522 not responding"));
    blink(PIN_LED_RED, 5, 60, 60);
    BEEP_DENIED();
    return;
  }

  if (store.getUChar("magic", 0) != NVS_MAGIC) enrollMaster();

  uint8_t uid[7]; uint8_t len;
  uint8_t lastUid[7] = {0}; uint8_t lastLen = 0;
  uint32_t lastReadAt = 0;
  uint32_t windowStart = millis();
  uint32_t btnDownAt = 0;

  digitalWrite(PIN_LED_GREEN, HIGH); delay(60); digitalWrite(PIN_LED_GREEN, LOW);
  BEEP_WAKE();

  while (millis() - windowStart < SCAN_WINDOW_MS) {

    // RED button: tap = cancel the window, hold ADMIN_HOLD_MS = admin mode
    if (digitalRead(PIN_ADMIN_BTN) == LOW) {
      if (btnDownAt == 0) btnDownAt = millis();
      else if (millis() - btnDownAt >= ADMIN_HOLD_MS) {
        runAdminMode();
        return;
      }
    } else {
      if (btnDownAt != 0) {
        DBGLN(F("[scan] cancelled (red)"));
        blink(PIN_LED_RED, 1); beep(150);
        return;
      }
      btnDownAt = 0;
    }

    if (!readTag(uid, &len, 300)) continue;

    bool same = (len == lastLen) && (millis() - lastReadAt < SAME_UID_LOCKOUT_MS);
    if (same) for (uint8_t i = 0; i < len; i++) if (uid[i] != lastUid[i]) { same = false; break; }
    if (same) continue;
    memcpy(lastUid, uid, len); lastLen = len; lastReadAt = millis();

#ifdef DEBUG
    DBG(F("[scan] uid="));
    for (uint8_t i = 0; i < len; i++) { DBG(uid[i] < 16 ? "0" : ""); Serial.print(uid[i], HEX); }
    DBGLN("");
#endif

    if (isAuthorized(uid, len)) {
      DBGLN(F("[auth] OK -> unlock"));
      fireUnlock();
      BEEP_OK();
      digitalWrite(PIN_LED_GREEN, HIGH); delay(1000); digitalWrite(PIN_LED_GREEN, LOW);
      return;
    } else {
      DBGLN(F("[auth] denied"));
      blink(PIN_LED_RED, 2);
      BEEP_DENIED();
    }
  }
  DBGLN(F("[scan] window expired"));
}

// ----------------------------------------------------------------------
// Deep sleep resets the chip, so setup() IS the main loop: it runs one scan
// window per wake and then sleeps again. loop() is never reached.
void setup() {
  pinMode(PIN_WAKE_BTN, INPUT_PULLUP);
  pinMode(PIN_ADMIN_BTN, INPUT_PULLUP);
  pinMode(PIN_SOLENOID, OUTPUT);   digitalWrite(PIN_SOLENOID, LOW);
  pinMode(PIN_BUZZER, OUTPUT);     digitalWrite(PIN_BUZZER, LOW);
  pinMode(PIN_LED_RED, OUTPUT);    digitalWrite(PIN_LED_RED, LOW);
  pinMode(PIN_LED_GREEN, OUTPUT);  digitalWrite(PIN_LED_GREEN, LOW);
#if READER_POWER_GATED
  pinMode(PIN_READER_PWR, OUTPUT); digitalWrite(PIN_READER_PWR, HIGH);   // reader off
#endif

  analogReadResolution(12);
  analogSetAttenuation(ADC_11db);          // full 0–3.3 V range on A0

#ifdef DEBUG
  Serial.begin(115200);
  uint32_t t0 = millis();
  while (!Serial && millis() - t0 < 1500) { }   // USB CDC needs a moment, but don't hang on battery
  DBGLN(F("\n[boot] RFID bike lock — Nano ESP32"));
  DBG(F("[boot] wake cause = ")); DBGLN((int)esp_sleep_get_wakeup_cause());
#endif

  store.begin("biketags", false);          // NVS namespace, read/write

  // Factory reset: hold BOTH buttons while pressing the board's reset, or while
  // powering up. Wipes the master and every enrolled tag.
  if (digitalRead(PIN_WAKE_BTN) == LOW && digitalRead(PIN_ADMIN_BTN) == LOW) {
    delay(1500);                                       // must be held, not brushed
    if (digitalRead(PIN_WAKE_BTN) == LOW && digitalRead(PIN_ADMIN_BTN) == LOW) {
      store.clear();
      DBGLN(F("[reset] tag store cleared — next wake re-enrolls the master"));
      blinkAlternating(10);
      beep(200, 3, 120);
      goToSleep();
    }
  }

#if DEV_NO_SLEEP
  while (true) {                           // USB stays alive; uploads work normally
    runScanWindow();
    idleUntilWake();
  }
#else
  runScanWindow();
  goToSleep();                             // ---- never returns ----
#endif
}

void loop() { }                            // unreachable in both paths

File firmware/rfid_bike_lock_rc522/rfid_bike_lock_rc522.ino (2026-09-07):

/*
 * RFID Bike Lock — v1 firmware
 * Target: Arduino Nano (ATmega328P, 5V/16MHz)
 * Reader: MFRC522 (the "RC522" Arduino kit board) on hardware SPI - see firmware/README.md
 * This is the RC522 variant of rfid_bike_lock.ino: identical state machine and EEPROM layout;
 * pins and behaviour; only the reader driver differs. Reads MIFARE Classic fobs and NTAG213
 * stickers (both ISO 14443A). It cannot talk to phones (that needs a PN532 + HCE) - same
 * key plan either way: fobs + a sticker on the phone case.
 *
 * Implements the state machine from DESIGN.md §5:
 *   SLEEP -> (wake button) -> SCAN (10 s) -> AUTH -> UNLOCK pulse -> SLEEP
 *   plus first-boot master enrollment and button-hold admin (add/remove tags).
 *
 * Power design notes (matches DESIGN.md §4):
 *   - Two panel buttons: GREEN = wake/scan (D3, the only sleep wake source),
 *     RED = cancel the scan window (tap) or enter admin mode (hold 5 s) on D2.
 *   - ACTIVE buzzer on D6: chirp on wake, double on unlock, long buzz on denied.
 *   - The RC522's 3.3 V supply is hard-switched by a P-MOSFET on PIN_READER_PWR
 *     (drive LOW to power the reader, HIGH/idle = off).
 *   - Between events the MCU sits in power-down sleep; the wake button on
 *     D3 (INT1) is the only wake source.
 *   - The solenoid fires for SOLENOID_PULSE_MS only after a successful auth.
 */

#include <SPI.h>
#include <MFRC522.h>          // Library Manager: "MFRC522" by GithubCommunity (miguelbalboa)
#include <EEPROM.h>
#include <avr/sleep.h>
#include <avr/power.h>

// ---------- Debug ----------
// Comment out for the battery-powered unit: Serial keeps the USB chip busy
// and the prints cost power. Leave on for bench bring-up.
#define DEBUG

#ifdef DEBUG
  #define DBG(x)   Serial.print(x)
  #define DBGLN(x) Serial.println(x)
#else
  #define DBG(x)
  #define DBGLN(x)
#endif

// ---------- Pins (DESIGN.md §4.2) ----------
const uint8_t PIN_WAKE_BTN   = 3;   // INT1: GREEN button to GND, internal pullup (wake + scan)
const uint8_t PIN_ADMIN_BTN  = 2;   // INT0: RED button to GND, internal pullup (tap = cancel, hold = admin)
const uint8_t PIN_BUZZER     = 6;   // ACTIVE buzzer (+) here, (-) to GND; HIGH = sound
const uint8_t PIN_SOLENOID   = 5;   // IRLZ44N gate (HIGH = solenoid energized)
const uint8_t PIN_READER_PWR  = 7;   // P-MOSFET gate (LOW = reader powered) - name kept for the PN532 build
const uint8_t PIN_RC522_SS   = 10;  // SPI: SS=D10, SCK=D13, MOSI=D11, MISO=D12 (hardware SPI)
const uint8_t PIN_RC522_RST  = 4;   // D9 is the green LED, so RST moves to D4
const uint8_t PIN_LED_RED    = 8;
const uint8_t PIN_LED_GREEN  = 9;
const uint8_t PIN_VBAT_SENSE = A0;  // battery / 2 via 100k:100k divider

// ---------- Tuning ----------
const uint32_t SCAN_WINDOW_MS      = 10000; // reader live after wake press
const uint32_t SOLENOID_PULSE_MS   = 300;   // unlock pulse
const uint32_t ADMIN_HOLD_MS       = 5000;  // button hold to enter admin
const uint32_t ADMIN_TIMEOUT_MS    = 15000; // idle exit from admin mode
const uint32_t SAME_UID_LOCKOUT_MS = 2000;  // ignore repeat reads of same tag
const float    VBAT_LOW            = 3.50;  // red triple-blink threshold (V)
const float    VBAT_DIVIDER        = 2.0;   // 100k:100k
const float    VREF                = 5.0;   // Nano ADC ref = 5V rail

// ---------- EEPROM layout ----------
// [0]        magic (EE_MAGIC when initialized)
// [1]        count of authorized slots in use (0..MAX_TAGS)
// [2..9]     master tag:      [len][uid bytes, zero-padded to 7]
// [10..]     MAX_TAGS slots:  [len][uid bytes, zero-padded to 7] each
const uint8_t  EE_MAGIC      = 0x42;
const int      EE_ADDR_MAGIC = 0;
const int      EE_ADDR_COUNT = 1;
const int      EE_ADDR_MASTER= 2;
const int      EE_ADDR_SLOTS = 10;
const uint8_t  UID_REC_SIZE  = 8;   // 1 len byte + up to 7 uid bytes
const uint8_t  MAX_TAGS      = 10;

MFRC522 rfid(PIN_RC522_SS, PIN_RC522_RST);

// ----------------------------------------------------------------------
// Wake interrupt — body intentionally empty; its only job is to end sleep.
void wakeISR() {}

// ---------- LED helpers ----------
void blink(uint8_t pin, uint8_t times, uint16_t onMs = 120, uint16_t offMs = 120) {
  for (uint8_t i = 0; i < times; i++) {
    digitalWrite(pin, HIGH); delay(onMs);
    digitalWrite(pin, LOW);  delay(offMs);
  }
}

void blinkAlternating(uint8_t cycles) { // admin-mode signature: red/green
  for (uint8_t i = 0; i < cycles; i++) {
    digitalWrite(PIN_LED_RED, HIGH);  delay(100);
    digitalWrite(PIN_LED_RED, LOW);
    digitalWrite(PIN_LED_GREEN, HIGH); delay(100);
    digitalWrite(PIN_LED_GREEN, LOW);
  }
}

// ---------- Battery ----------
float readBatteryVolts() {
  analogRead(PIN_VBAT_SENSE);              // throwaway read after sleep (settles mux)
  int raw = analogRead(PIN_VBAT_SENSE);
  return raw * (VREF / 1023.0) * VBAT_DIVIDER;
}

// ---------- EEPROM tag records ----------
void eeWriteRecord(int addr, const uint8_t *uid, uint8_t len) {
  EEPROM.update(addr, len);
  for (uint8_t i = 0; i < 7; i++) EEPROM.update(addr + 1 + i, i < len ? uid[i] : 0);
}

bool eeMatchRecord(int addr, const uint8_t *uid, uint8_t len) {
  if (EEPROM.read(addr) != len) return false;
  for (uint8_t i = 0; i < len; i++)
    if (EEPROM.read(addr + 1 + i) != uid[i]) return false;
  return true;
}

bool isMaster(const uint8_t *uid, uint8_t len) {
  return eeMatchRecord(EE_ADDR_MASTER, uid, len);
}

// Returns slot index 0..count-1, or -1 if not found.
int findTag(const uint8_t *uid, uint8_t len) {
  uint8_t count = EEPROM.read(EE_ADDR_COUNT);
  if (count > MAX_TAGS) count = 0; // corrupt guard
  for (uint8_t s = 0; s < count; s++)
    if (eeMatchRecord(EE_ADDR_SLOTS + s * UID_REC_SIZE, uid, len)) return s;
  return -1;
}

bool isAuthorized(const uint8_t *uid, uint8_t len) {
  return isMaster(uid, len) || findTag(uid, len) >= 0;
}

bool addTag(const uint8_t *uid, uint8_t len) {
  uint8_t count = EEPROM.read(EE_ADDR_COUNT);
  if (count >= MAX_TAGS) return false;
  eeWriteRecord(EE_ADDR_SLOTS + count * UID_REC_SIZE, uid, len);
  EEPROM.update(EE_ADDR_COUNT, count + 1);
  return true;
}

void removeTagAt(int slot) {
  uint8_t count = EEPROM.read(EE_ADDR_COUNT);
  // Move the last record into the freed slot, shrink count.
  int last = EE_ADDR_SLOTS + (count - 1) * UID_REC_SIZE;
  int dst  = EE_ADDR_SLOTS + slot * UID_REC_SIZE;
  for (uint8_t i = 0; i < UID_REC_SIZE; i++)
    EEPROM.update(dst + i, EEPROM.read(last + i));
  EEPROM.update(EE_ADDR_COUNT, count - 1);
}
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

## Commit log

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2026-07-13 Add v1 Arduino firmware and bench bring-up guide
    Complete sketch implementing the DESIGN.md state machine: power-down
    sleep with wake-button interrupt, P-MOSFET power-gated PN532 scanning
    in a 10s window, EEPROM-backed tag list with first-boot master
    enrollment and button-hold admin add/remove, 300ms solenoid unlock
    pulse, battery voltage check with low-battery warning, and same-UID
    debounce. Firmware README covers IDE setup, PN532 I2C DIP switches,
    staged bench bring-up with expected sleep currents, and factory reset.
    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
    [rfid_bike_lock.ino]
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2026-07-13 Build the CAD: fix geometry collisions, export STLs and preview renders
    Rendered and visually verified the model with OpenSCAD in-session.
    Fixes found by inspection: suitcase-lip closure replaces the
    slide-hook (a hinged clamshell closes on an arc, so the joint engages
    rotationally and the hidden bore screw clamps it); latch boss and
    solenoid pedestal now added after the pod-cavity subtraction so they
    survive; hinge knuckles get clearance cuts for the opposing half; the
    spool cover clears the frame-tube arc and is retained by the hinge
    pin; lid corner screws land in real bosses; liner gets 0.15mm radial
    print clearance. Exports: seven print-ready STLs in cad/stl/ and four
    verification render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
    [bike_lock.scad, lid.stl, liner_left.stl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]
2026-07-13 CAD v0.2: industrial-design pass with modeled wiring infrastructure
    Restructures the housing per FDM design-for-manufacturing and product
    design practice: one radius family with universal edge breaks, drafted
    pod walls giving uniform ~3mm thickness, a full wrap-around belt band
    whose left half IS the closure skirt (part line becomes a design line
    with a 0.8mm shadow gap), pod-to-tube and drum-to-body fairings with
    <=45 degree overhangs, embossed NFC target ring, recessed button dish,
    countersunk lid screws, sheltered USB niche, and a cable-exit snout.
    Functional fixes found during the pass: solenoid body was 1.5mm taller
    than the pod interior (groove seat deepened to 11.5mm); side and drum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
    [bike_lock.scad, lid.stl, shell_left.stl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]
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2026-07-13 Fix multi-body STEP exports that hung SolidWorks import
    Three parts exported as compounds of disconnected solids, spawning one
    Open CASCADE translator per body in SolidWorks: the liner fins only
    touched the base ring on a knife edge (15 bodies per liner half), the
    shim shared the fin bug, and the lid's PN532 posts floated 0.6mm short
    of the underside. Fins now root 1.7mm into the ring so each liner
    fuses to one solid; seam-crossing fin-tip slivers are dropped by a
    largest-solid filter; the lid posts are deleted in favor of the pocket
    walls + foam tape (posts cannot physically reach the lid through the
    board pocket). The exporter now fuses stragglers and refuses to export
    any part that remain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
    [lid.step, lid.stl, liner_left.step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]
2026-07-14 Add positioned STEP assembly file of all v0.4 components
    cad/step/bike_lock_assembly.step: full assembly with all 12 parts
    located and colored (shells, bay, hatches, lid, pedestal, liners,
    spool cover, hinge end plugs), exported via cq.Assembly so SolidWorks
    opens it as an assembly with components in place. Verified by
    re-import (12 solids, correct bounding box).
    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
    [bike_lock_assembly.step]
2026-07-14 Add combined multibody STEP as a robust alternative to the assembly STEP
    Some SolidWorks import configurations (3D Interconnect) open the
    CadQuery assembly-tree STEP blank. bike_lock_combined.step carries the
    same 12 positioned parts as a single multibody file, which imports
    through the same code path as the individual part files. README
    documents both files and the Interconnect workaround.
    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
    [bike_lock_combined.step]
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2026-07-14 CAD v0.5 'spine + door': consumer-install architecture, machine-verified kinematics
    Assembly review found v0.4 could not be installed: the pod overhung the
    seam and the full-width bay blocked both the door swing and the tube
    entry. v0.5 restructures around three kinematic rules: (1) the tube
    entry corridor (a +/-23.5mm swept slab left of the seam) contains no
    fixed material - the pod becomes asymmetric with its left fringe
    floating above the closed door, and the belt/left fairing are deleted;
    (2) the door is a light arc panel (liner half + closure flange/lip
    engaging through analytically-swept sector pockets) with pod, bay, and
    drum all right of y+7, outside its swing; (3) the drum turns 90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
    [01_body.step, 01_shell_right.step, 02_door.step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]
2026-07-14 Fix all seven static interferences; add pairwise --matrix verification
    A full pairwise interference matrix over the placed assembly found
    seven clashes: the pedestal cart overlapped the latch boss column
    (scalloped +0.5 clearance), body and door were 162mm long from a
    construction artifact (trimmed to the true 150 with proper end faces),
    the hinge end plugs' flanges dug into undersized counterbores (08.4 x
    1.4 flange recesses added, plugs re-seated flush), the bay's web poked
    1mm below the brick floor into the hatch (shortened), and the spool
    cover rabbet was cut before the web union so the web filled it (rabbet
    cut moved after all unions; cover re-seated with 0.2 axial clearance).
    One shar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
    [01_body.step, 02_door.step, 03_bay_module.step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]
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2026-07-15 v0.6 S2-S7: fastening completeness, single hinge rod, spine raceway+cover, liner dovetails, bay repack
    Fixes 12 machine-confirmed defects (D1-D12, see PR body): the broken consumer
    closure-screw path and its through-punched insert pocket (rebuilt per judge-
    probed geometry: low insert pad z21.8-25.2 + M4x8 + short M4xL3 heat-set,
    3.7mm solid bore floor restored); lid screws that landed over open cavity and
    through the PN532 window (4 rim bosses with M3 heat-sets at x50/114); spool
    cover screws that threaded into the drum void (relocated r31.25, clocked
    90/210/330, countersunk flush via nested pads); bay M4 heads proud into the
    liner zone (counterbores deepened); the hatch that covered a soli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
    [bay_hatch.step, bay_hatch.stl, bay_module.step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]
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2026-07-15 v0.6 final-review fixes: unblock the closure screw path (again), screw-path verification, review cleanups
    The post-implementation Opus review found the closure clearance cut was
    applied to the boss sub-solid BEFORE body.union(boss) - the union refilled
    the column where the shell wall is solid (z26.5-29.5), leaving a 3mm plug on
    the consumer screw's axis. Same defect class as v0.5's D1, relocated. The cut
    now runs on body after the union; probed clear z25.7-30.
    Because no screw is a modeled part, no existing check could see this: --gaps
    gains SCREW-PATH PROBES - membership cylinders along each critical screw axis
    that must be air (closure shank + insert reach, tail-cap pilot alignment +
    cap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
    [01_body.step, 02_door.step, 03_bay_module.step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]
2026-07-15 v0.7: electronics reference bodies, tray cartridges, packaging verification (gate run in progress)
    Every BOM electronic is now a dimensioned placed body (nominal, VERIFY on
    arrival): Nano, MT3608+perfboard stack, TP4056, PN532, LiPo, solenoid
    (+plunger TRIMMED to x98 - untrimmed it hits the wake button), button, LEDs.
    Packaging claims become machine-checked --gaps assertions (solenoid vs lid
    >=1.0, plunger-tail vs button >=1.0, etc), numbered 90+ in step/placed/ for
    SolidWorks placement work.
    Modeling exposed two more v0.5 impossibilities, both fixed:
    - D13: the TP4056 vertical card slot pointed its USB-C at the floor. Board
    now lies FLAT in a rail cradle (lane y=22, clear of the edge-sta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
    [bay_hatch.step, bay_hatch.stl, bay_module.step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]
2026-07-15 v0.7 layout v3 (gate iteration): pod-side Nano sled, vertical perf rack, long-edge TP4056, tower-mounted MT3608
    The packaging gate rejected layout v2 wholesale (shelf/cell/nano collisions
    up to 3293 mm^3) and taught the bay's real shape: its cross-section is a
    WEDGE (the clamp bore eats the top toward -Y), and Nano + MT3608 + perfboard
    cannot coexist in it. Layout v3:
    - Nano moves to the POD on a diagonal crown-bridging sled (most of its
    signals terminate up top anyway - spine harness drops ~11 -> ~6 wires)
    - perfboard stands vertical against the -Y wall, CUT to 40x23 (the wedge
    caps board height at z-30 near the wall), cap mounted lying (8.5 stack)
    - TP4056 stands on its LONG edge (v0.5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
    [bay_hatch.step, bay_hatch.stl, bay_module.step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]
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2026-07-16 v0.7 WIP: nano edge-stand in pod wall recess + clamp bar; PN532 corner reliefs
    The bare Nano fits NOWHERE flat: the pod interior (45.6x40.2 at floor level)
    rejects a 45x18 rectangle at every rotation angle, and the tray is owned by
    the perf rack, TP4056 lane, and the edge-standing cell. Solution mirrors the
    MT3608 pattern: the board stands on edge along the pod's +Y wall in a 1.6mm
    recess (x2..47 - the 45mm board fits exactly), SMD face inward, USB shell at
    the x39..47 end clear of the spine feed hole, held by a screwed clamp bar
    (nano_clamp, part 15) riding two crown bosses.
    PN532: straight wall recesses missed the drafted interior corner arcs (r9)
    that bulge into the board's corners - cor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
    [body.step, body.stl, mock_nano.step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]
2026-07-16 v0.7: electronics packaging machine-verified - mockups, holders, gate green (0/292)
    Every BOM electronic is a placed reference body; every board has a fastened
    home: perf_rack (vertical 40x23 cut board vs the bay wall), nano_clamp
    (edge-standing Nano in a pod wall recess, clamp bar on crown bosses, part 15),
    TP4056 flat cradle (USB correctly through the wall), MT3608 end-posts on the
    pedestal tower, edge-standing LiPo. Stepped closure flap restored (owner
    request): visible extension under the latch to y16.5 at z<=23.5 - sweep-safe
    (peaks z26.2, 3.8mm clamp floor kept), roots into the door shell wall.
    Packaging defects this pass surfaced and fixed: D13 (TP4056 slot pointed the
    USB at the flo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
    [01_body.step, 02_door.step, 03_bay_module.step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]
2026-07-17 releases/v0.7: labeled release snapshot (placed STEPs, STLs, renders, docs, manifest)
    Every part file carries the _v07 label; MANIFEST.md gives the full labeled
    part table (14 printed + rod + shim + 10 electronics reference bodies), the
    gate state at freeze, and insert order. Live cad/ exports stay unversioned
    (the toolchain regenerates them); this folder is the fixed reference set.
    cad/README part table rows labeled (v0.7).
    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
    [01_body_v07.step, 02_door_v07.step, 03_bay_module_v07.step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]
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2026-07-20 v0.8: all-M3 heat-set fastening rebuild + releases/v0.8
    Owner request: switch every threaded joint to an M3 machine screw into an M3
    brass heat-set insert for a super-refined printed prototype - no self-tapping
    into plastic anywhere. Two carve-outs, both forced by an external part:
    - Solenoid stays M2.5 (the JF-0530B's own tabs are drilled M2.5; an M3 screw
    won't pass) -> M2.5 brass heat-set.
    - PN532 stays M3 NYLON into printed bosses (brass at the 4 antenna corners sits
    in the 13.56MHz loop and kills read range; all 4 corners, no safe subset).
    Conversions (12 joint types):
    - closure screw M4 -> short M3 heat-set (O4.0xL3.8; the door pad is only 3.4mm
    deep, too shallow for a full 6.5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
    [01_body_v08.step, 02_door_v08.step, 03_bay_module_v08.step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]
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2026-07-21 v0.8.2: move driver card to the pedestal cart (Option C); delete body bracket
    Per the packaging analysis, the driver stage now rides the pedestal-cart's -Y
    platform instead of a contorted body bracket:
    - cart gains a 3mm -Y platform (to y-13) + two short-M3 heat-set bosses (O8,
    hang to z31 so the 3.8 insert has full grip; stays above the door swing)
    - the body's shelf+tie+leg bracket (which threaded the 1mm door/cart gap) is
    removed entirely
    - driver mock, DRV_SEAT, support registry entry, and the body/cart contact gap
    specs all follow the move; stale mock docstring (25x16.5) corrected to 42x10.7
    Why: puts the driver in a tiny flyback loop with the solenoid the cart carries,
    a solid m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
    [01_body.step, 01_body_v08.step, 02_door.step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]
2026-07-23 v0.8.3: environmental + DFM + power hardening (hard critique pass)
    Multi-domain critique of the whole design; every finding fixed in CAD and
    machine-verified, or resolved in docs:
    WATER (previously unaddressed anywhere):
    - latch-bore weep O2.2 (the O11x26 bore is open to the sky; pooled rain on the
    plunger = freeze-jam risk) -> drains into the tube bore, offset clear of the
    screw axis and the screw-path probe
    - drum-void weep O2.5 (snout enters at z~-74, void bottoms at -90.5: a 16mm
    bucket under the donor spring) -> drains at the ring's lowest point
    - new usb_plug printed TPU part: squish-fit plug for the bay USB-C port
    (wheel-spray zone), flange + pull tab + lanyard hole
    - documen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
    [01_body_v08.step, 02_door_v08.step, 03_bay_module_v08.step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]
2026-07-23 Repo reorg: iteration-labeled STEP-only releases + README index
    Per owner request - one branch, clear per-iteration organization, STEP files
    only for each iteration:
    - releases/v0.8 -> releases/v0.8.3 (matches its actual state); all files
    relabeled _v083; fresh export of all 24 placed parts + assembly + combined
    + coupon + shim + usb_plug
    - releases now STEP-only: dropped stl/, docs/ snapshots, renders/ from v0.7
    and v0.8.3 (git history preserves every byte); same trim in cad/archive
    - root step/ and stl/ build outputs gitignored (regenerable from source)
    - README: rewritten repo map + newest-first iteration index v0.2 -> v0.8.3,
    stale battery/CAD-version references fixed
    Co-Authore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
    [01_body_v08.step, 01_body_v083.step, 02_door_v08.step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]
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2026-07-23 v0.8.3b: replace stepped PN532 wall reliefs with one continuous board-seat rebate
    The pod's top-wall corners showed divots (owner-flagged): the PN532 reliefs
    were five separate stepped box cuts with raw mid-wall terminations. Now ONE
    rebate prism following the interior's rounded contour (+1.8/side, r4 corners
    to clear the board's square corners), ending at the x=50 lid-boss centerlines
    so the steps are swallowed by the bosses. Same function, clean continuous
    ledge. Re-gated: gaps 0/292, support 0/27, matrix 0. newest-design/ STEPs
    refreshed in place.
    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
    [01_body_v083.step, 02_door_v083.step, 03_bay_module_v083.step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]
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2026-07-24 INTERNALS.md + internals renders: electronics mating documentation
    Per-component mating guide (contact faces, fasteners, positions, wiring paths)
    keyed to 5 new documentation renders in renders/internals/ (pod deck top-down,
    pedestal-cart drop-in module, RFID layer with lifted lid, battery bay open,
    hatch tray). Adds render_internals.scad view file. Also records the measured
    solenoid clearances (cart contact = bolted joint, cable head 0.10 designed
    engagement, all others >=0.30, zero interpenetrations).
    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
    [render_internals.scad]
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2026-09-03 Latch mechanism cutaway animation (28-frame GIF + locked-state still)
    Sectioned at the bore centerline from the real CAD geometry, with honest cam
    kinematics per DESIGN 6.4: 45deg nose cams the plunger back on insert, plunger
    snaps into the ring groove (zero-power lock), solenoid pulse retracts it, the
    ejector spring pops the head clear, spool retracts. render_latch_anim.scad
    regenerates it (F=0..27).
    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
    [render_latch_anim.scad]
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2026-09-06 CNC casing: first parametric model (cad/cnc_casing_cq.py) + STEP set + gates green
    Implements CNC_CASING 2A: 2.5"x3/16" tube halves line-bored to O54 (vertical
    seam, bottom hook tongue/groove, rear liner lip), inside-out M3 counterbored
    attachment rows (vertical crown y+6, horizontal skirt z+-8), saddle+skirt top
    box with latch boss/O11 bore/plunger channel and tapped-pilot lid bosses, lid
    plate with RF window bezel step, steel closure block on C2 taking an M4 closure
    screw, top-loaded spool box with bushed exit (no cover plate), split TPU liner.
    Gates: 0 clashes, counterbore walls 7.3/2.8mm, screw paths clear. Doc corrected:
    O60x5 stock would have bored O50 (too small) -> 2.5"x3/16"; flat l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
    [render_cnc.scad]
2026-09-06 CNC casing rev 2: slide-and-lift install (two hooks + one guarded M3), owner decisions applied
    The swing gate proved the bottom-seam hinge could not coexist with a spool box under
    the seam (C2's lower quadrant sweeps down into it; a real install would need ~100 deg).
    C2 now installs by translation: slide in sideways 2.5 mm low, then the single guarded
    closure screw lifts it 2.5 mm so the closure block rises behind A1's lip and a new K
    hook block on C2 rises behind A3's lip. Both hooks are plain milled rectangles.
    Model (cad/cnc_casing_cq.py):
    - delete hook tongue/groove; add K_hook_block (J-profile, 2x M3 from inside C2)
    - A1: hook pocket + lip under the -y overhang, flat sweep clearance at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
    [A1_top_box.step, A2_lid.step, A3_bottom_box.step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]
2026-09-06 CNC casing rev 3: real bottom hinge (O5 pin + knuckles), 90 deg swing and frame-entry gated
    Owner wants a hinged clamshell: open, drop on the down tube, swing shut, one screw that is
    only reachable through the latch bore when unlocked. Rev 2's slide-and-lift is retired.
    Hinge: O5 dowel along the tube at y -1 / z -38 (1 mm onto the C2 side, 6 mm under the tube).
    Two O11 lugs on the spool box A3 (x 58-66, 90-98), one lug on a hinge block bolted to C2
    from inside (replaces the K hook block). Everything near the pin is round about it, and the
    spool box body sits wholly at y >= 0.5, so a 90 deg swing never enters it by construction.
    Pin at y -1 keeps every closure-block point at y <= pin-y so no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
    [A1_top_box.step, A2_lid.step, A3_bottom_box.step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]
2026-09-06 CNC casing rev 3: real hinge pin + knuckles, slim round spool puck, O4 cable
    Owner wants a consumer-hinged clamshell with the one closure screw still guarded by
    the cable head. The bottom-seam tongue "hinge" and the rev 2 slide-and-lift are both
    retired for a real hinge:
    - O5 pin along the tube at y -1 / z -38 (1 mm onto the C2 side, 6 mm under the tube):
    every non-round point of C2's hardware stays on its own side of the seam through a
    90 deg swing, so the spool box is never entered; the closure block never rises into
    the A1 roof as the swing starts
    - two O11 lugs on A3, one on a hinge block bolted to C2 from inside; blind pin bore
    (drilled through lug 1, stops 2 mm short of lug 2's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
    [A1_top_box.step, A2_lid.step, A3_bottom_box.step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]
2026-09-06 CNC casing rev 3b: spool puck centred under the tube, 60 deg hinge opening with puck-top stop
    Owner: "make the drum vertical and partially/fully centred but keep clearance for the
    shell opening". Sampled C2's full swing envelope under the seam: up to 60 deg nothing
    on C2 dips below z -50.1 anywhere, so the O62 puck now sits centred under the tube
    (O62 inside the O63.5 tube width - nothing sticks out sideways) with its pocket
    ceiling at -54 and its flat top at -51.5 doubling as the hinge stop (C2 lands on it at
    64 deg, gated). 60 deg gives a 65 mm mouth between the rims; a O46 down tube enters
    along the mouth bisector with 0.00 mm^3 contact (frame-entry gate rewritten to follow
    the bisector i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
    [A1_top_box.step, A2_lid.step, A3_bottom_box.step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]
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2026-09-06 CNC casing: v0.8 angled fins back on the liner + snap-stud retention (workshop)
    Liner halves return to the v0.8 profile (24 fins x 12 tall x 1.4, 30 deg lean, 2 mm base
    ring; slivers cut by the seam plane dropped). Retention: 4 TPU snap studs per half
    (O4.0 x 1.8) into blind O4.2 x 2 holes drilled from inside the tube halves, sited 28 deg
    from both screw rows. New gate checks each stud seats 0.2 short of its hole floor; all
    gates green. CNC_CASING 2A gains a liner-retention option table (screws through the
    liner rejected, adhesive/dovetail/lips weighed, studs chosen) and D11.
    Claude-Session: https://claude.ai/code/session_01Rpp78CApKp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
    [A1_top_box.step, A2_lid.step, A3_bottom_box.step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]
2026-09-06 Liner studs at print size (O4.5 into O4.2, 0.3 press fit); matrix gate checks the designed interference volume; drawings carry the fit callouts
    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
    [A1_top_box.step, A2_lid.step, A3_bottom_box.step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]
2026-09-06 Liner: 6 press-fit studs per half (-45/0/+45 from mid-arc), designed-interference gate uses embedded depth; docs + drawings follow
    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
    [A1_top_box.step, A2_lid.step, A3_bottom_box.step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]
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2026-09-06 CNC casing rev 3c: electronics stack-up as gated reference bodies; A1 grows to 135 x 57
    Owner: prove everything fits. Every purchased part is now a ref_* body at its real envelope
    (103450 cell, PN532, printed tray, cart+solenoid+driver module, plunger, Nano on edge,
    TP4056 with its USB-C, MT3608, sealed button, 2 LEDs), exported with the STEP set and
    checked by the interference matrix plus a new clearance report (gaps < 1 mm listed).
    What the stack-up forced: A1 x 10..145 / y -14..43 (interior 129 x 51 x 24), latch bore
    x 78 -> 85 (battery clears the boss), pocket corners R4, lid screws 3 corners + one
    mid-wall at x 100 (the USB-C owns the +x/+y corner), A1 chassis row x 25/70/130, button
    (7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
    [A1_top_box.step, A2_lid.step, A3_bottom_box.step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]
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2026-09-07 Add red button (D2: tap cancels, hold enters admin), active buzzer (D6) and side-by-side LEDs
    Housing: second O12 button hole, LED pair, O2.5 buzzer sound hole in the lid; buzzer body
    placed over the MT3608 as a reference body. Firmware: RC522 sketch gains PIN_ADMIN_BTN,
    PIN_BUZZER, beep() + BEEP_* patterns (wake chirp, double on unlock, long buzz on denied,
    three on admin, long on low battery); reader helpers renamed readerOn/readerOff. README
    gains a panel-I/O table and the passive-buzzer swap; BOM 12/12b updated. Stack-up gates green.
    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
    [A1_top_box.step, A2_lid.step, A3_bottom_box.step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]
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2026-09-07 Refit A1's interior around the MEASURED HS-0730B solenoid (28.6 x 17.5 x 12.7)
    The delivered solenoid is 4.5 mm wider than the modelled one, which pushed it 1.75 mm through
    A1's -y interior wall. Widening the box was tried first and fails: at BY0=-17 the C2 swing
    clashes (35 mm^3) and the O46 frame-entry mouth closes up (171 mm^3). Instead A1 gets a LOCAL
    POCKET in that wall over the solenoid zone, leaving 1 mm of wall - no change to the outer
    envelope and the swing/frame gates stay at 0.00.
    Interior re-laid-out in three z layers on the +x half, since the bigger coil no longer leaves
    a single-file +y strip: solenoid on two pillars (both -x of x=115) so the TP4056 tucks under
    the coil; Nano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
    [A1_top_box.step, A2_lid.step, A3_bottom_box.step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]
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2026-09-07 Port the firmware to the Arduino Nano ESP32 (the board actually on hand)
    firmware/rfid_bike_lock_esp32/: same state machine, keys and behaviour; the differences are
    platform plumbing. Deep sleep resets the chip, so the scan window lives in setup() and the
    sketch sleeps at the end of it with ext0 wake on the green button; tags move from AVR EEPROM
    to Preferences/NVS keeping the 8-byte record layout; the ADC becomes 12-bit against 3.3 V so
    the battery maths change while the 100k:100k divider does not. Adds a factory reset: hold both
    buttons through power-up for 1.5 s.
    Reader power gating is compiled out by default - the delivered IRF4905's -2..-4 V threshold is
    marginal when 3.3 V logic can o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
    [rfid_bike_lock_esp32.ino]
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
